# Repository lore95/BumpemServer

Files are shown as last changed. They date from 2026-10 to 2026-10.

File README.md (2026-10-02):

# bumpem

Host software for the IBMS Bump'em multi-directional perturbation system.

## Quick start
```sh
git clone <repo> && cd bumpem
python -m venv .venv && source .venv/bin/activate   # or conda
pip install -e ".[dev]"
pytest                                   # no hardware needed
bumpem monitor --sim                     # simulated board
```

## With hardware
No person attached for first tests. Stop the treadmill before `release` or `estop`.
```sh
pip install platformio
scripts/flash.sh                         # firmware v1  (scripts/flash.sh legacy = v0 reference)
bumpem ports                             # find the Teensy
bumpem info  --port /dev/tty.usbmodemXXXX
bumpem arm   --port /dev/tty.usbmodemXXXX --watch 3     # ramp to 5 N baseline
bumpem pulse A=95 --rise 50 --dur 600 --fall 0 --port /dev/tty.usbmodemXXXX --watch 2
bumpem release --port /dev/tty.usbmodemXXXX              # ramp to 0, drivers off
bumpem estop   --port /dev/tty.usbmodemXXXX              # drivers off now
```
Pulse amplitudes are relative to baseline. Protocol and parameters: `docs/PROTOCOL.md`.

ESCON setup is still done once in ESCON Studio. See `escon/README.md` and `docs/thesis/manual.pdf` §4.3.1.

Docs: `docs/knowledge/` (system facts), `docs/PROTOCOL.md`, `docs/STATUS.md`.

## Server
```sh
pip install -e ".[server,dev]"
bumpem serve --board sim                      # or --board /dev/tty.usbmodemXXXX
```
Open http://127.0.0.1:8000/docs to try every endpoint from the browser. API contract: `docs/API.md`.
While the server runs it owns the serial port: stop the board through the API (`POST /api/v1/estop`), not the CLI.

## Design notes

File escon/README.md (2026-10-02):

# ESCON configuration

**Model: maxon ESCON 70/10, part 422969** (label on the driver, photo `docs/hardware-photos/2026-09-29_escon-7010-connectors.jpg`).
Hardware reference: `ESCON-70-10-Hardware-Reference-rel9079.pdf` (maxon, 2021-08).

## I/O pins used by Bump'em (hardware reference Tables 3-17, 3-19)
| Connector | Pin | Signal | Bump'em use |
|---|---|---|---|
| J5 Digital I/O | 1 | DigIN1 | not used by the manual's wiring |
| J5 | **2** | **DigIN2** | enable ← Teensy 27/28/29/30 |
| J5 | 3, 4 | DigIN/DigOUT3, 4 | not used |
| J5 | **5** | **GND** | → ground distributor |
| J5 | 6 | +5 VDC aux out (≤ 10 mA) | **never to a Teensy pin** |
| J6 Analog I/O | 1, 2 | AnIN1+ / AnIN1− | not used by the manual's wiring |
| J6 | **3** | **AnIN2+** | setpoint ← DAC VA/VB/VC/VD |
| J6 | **4** | **AnIN2−** | → DAC GND |
| J6 | 5, 6 | AnOUT1, AnOUT2 (−4…+4 V) | **never to a Teensy pin** (negative voltage) |
| J6 | **7** | **GND** | → ground distributor |

Levels (§3.3.5–3.3.6): DigIN logic 1 > 2.4 V typ. (Teensy 3.3 V is enough), logic 0 < 1.0 V, switching delay < 8 ms.
AnIN ±10 V differential, 12-bit, 5.64 mV resolution (DAC 0–3.3 V is inside the range).

## Stanford reference configuration (`stanford/ESCON_Current_Ctrl_Config.edc`)
Downloaded 2026-09-30 from the "Config" link on https://biomechatronics.stanford.edu/bump-em (same Drive ID as manual §4.3.1).
Created 03.03.2020 for an **ESCON 70/10** with a maxon EC motor (Stanford: EC90 flat). Decoded values:
| Parameter | Value |
|---|---|
| Mode of operation | Current controller (speed limiter on) |
| Digital inputs configuration 0x00000010 | **DigIN2 = Enable**; DigIN1, 3, 4 = None |
| Analog inputs configuration 0x00000010 | **AnIN2 = Set value**; AnIN1 = None |
| Set value current | **0 V → 0 A, 10 V → 30 A (3 A/V)** |
| Max. output current limit / nominal current | 30 A / 4.06 A |
| Motor | maxon EC, 11 pole pairs, speed constant 42.1 rpm/V, 0.904 Ω, 0.892 mH, max 1960 rpm |
| Motor torque constant (tuning data) | 226.8 mNm/A |
| Analog outputs | not configured |

Nibble decoding (4 bits per input) is consistent with the manual on both fields (enable on DigIN2, setpoint on AnIN2).

**Conflict to resolve:** if the IBMS drivers carry this file (manual says to load it), the DAC's 0–3.3 V gives **0–9.9 A**, not 0–30 A as the firmware assumes (`i_full = 30`). Firmware current values are then 3.03× the real current. See `docs/STATUS.md`.

## Still to record
- ESCON Studio parameter file: not found. It can be **read back from each driver** with ESCON Studio (Windows, USB J7) and saved here. That also answers the next three lines.
- AnIN2 scaling (voltage ↔ current setpoint). Firmware assumes 3.3 V ↔ 30 A (`i_full`, `legacy/Arduino_Script.ino:242`).
- Current limit per module; which DigIN is configured as enable and which AnIN as setpoint (the manual says DigIN2 / AnIN2).
- Module (A/B/C/D) ↔ controller serial number ↔ last auto-tune date.

## Status LED (hardware reference p. 28, Table 3-23)
| Green | Red | Meaning |
|---|---|---|
| off | off | init |
| slow blink | off | disabled (ready, enable input low) |
| on | off | enabled |
| 2× | off | stopping / standstill |
| off | 1× | +Vcc over-/undervoltage, +5 V undervoltage |
| off | 2× | thermal overload, overcurrent, power stage protection, internal hardware |
| off | 3× | encoder / DC tacho cable break or polarity |
| off | 4× | PWM set value input out of range |
| off | 5× | Hall sensor pattern / sequence / frequency |
| off | on | auto-tuning identification, internal software |

Module C, 2026-10-01: **red steady, green off** = Auto Tuning Identification Error **or** Internal Software Error (Table 3-23, p. 29). Power stage off. Exact error to be read in ESCON Studio (status window). Do not run Regulation Tuning or a firmware update before diagnosing.

Module C, 2026-10-01 (later): red 1× (supply) error cleared after rework at J1, then **red 5× → ESCON Studio: "Hall Sensor Pattern Error: combination of Hall sensor signals invalid"**. Studio now connects.
J3 Hall plug (hardware reference Table 3-12): 1 Hall 1, 2 Hall 2, 3 Hall 3, 4 +5 V Hall supply (≤ 30 mA), 5 GND. Inputs have 2.7 kΩ pull-ups (p. 16): an unconnected Hall wire reads high.
Module C Controller Monitor (2026-10-01): Current Controller, DI2 = Enable, AI2 = Set Value, offset 0.0070 A, rotor position by digital Hall sensors, all other I/O unused → **matches the Stanford config** (`stanford/`). Caveat: an accidental Download on 2026-09-30 may have loaded that file. Config is not the cause of the Hall error.
ESCON Studio Diagnostics, module C (2026-10-01): motor test OK (motor turned → windings and power stage working). **Hall sensor connection test FAILED**; all three Hall states frozen while turning the drum by hand. Likely: Hall wires or Hall supply (+5 V / GND, J3 pins 4/5) broken or not connected; less likely: Hall sensors damaged. Next: J3 re-seat, cable inspection, J3 pin 4–5 ≈ 5 V, continuity J3 → motor.
**Cause found (2026-10-01): module C's J3 has wires only on pins 1–4; pin 5 (Hall GND) is empty** → Hall sensors unpowered → frozen signals, pattern error. Fix: identify the Hall cable's GND conductor from the motor's colour code (motor label → maxon datasheet), check pins 1–4 order, then connect GND to pin 5. Do not guess.
J3 (2026-10-01 photo): 1 yellow, 2 pink, 3 grey, 4 green, 5 empty; extension wires spliced under tape below J3 (pink is not a maxon Hall colour). maxon's internal Hall order is GND before +V Hall, ESCON J3 is +5 V (4) then GND (5): pin 4 may carry either. Identify via splice + motor datasheet before connecting pin 5.
**Motor model check:** maxon EC 90 flat 323772 (24 V) has 12 pole pairs, 135 rpm/V; the Stanford config says 11 pole pairs, 42.1 rpm/V → Stanford motor is another variant. Module C's motor label needed before any config download.
**Second module (2026-10-01): same J3 wiring (pin 5 empty) and same Hall error** → systematic, not a broken wire. Hypotheses: the Hall supply (GND or +V) was taken from the **distributor board** or from the **24 V supply** (RS-15-24, found disconnected). Check where the RS-15-24 outputs go and the motor's Hall supply range (datasheet, needs motor label).
Thesis check (2026-10-01): 24 V supply powers only the IAA100 (§2.7) → not the Hall supply. Hall wiring not described in the thesis; per maxon/ESCON docs, Hall GND belongs on J3 pin 5. Next: splice below J3, distributor board, motor label.
Motor identified (2026-10-01): **maxon EC 90 flat 500267** (260 W, 48 V, 11 pole pairs) → the Stanford config fits; no reload needed for the motor data. Hall colour code: from its catalog page (pending). maxon usually lists Hall GND before VHall; ESCON J3 has +5 V on 4, GND on 5 → J3 pin 4's green wire may be either. Do not connect pin 5 before checking.
Catalog page (2026-10-01): EC 90 flat 500267 = V1, 8-pin connector (Hall GND pin 6, VHall pin 3, 4.5–24 V). Module C: J2 has 4 wires (red, brown, white, **blue on shield pin 4**), J3 has 4 → 8 total = all motor pins present; **blue on J2.4 is most likely the Hall GND** → belongs on J3 pin 5. Confirm at the motor connector first.
Motor connector read (2026-10-01, mirrored wire-side numbering): blue = motor pin 6 = Hall GND, wired to J2 pin 4 (shield) instead of J3 pin 5; all other 7 wires correct. Fix: move blue to J3 pin 5. Possible reason it worked before: shield terminal → housing/earth → indirect ground path via Teensy/PC (unverified).
**Module C fixed (2026-10-01):** blue (Hall GND) moved from J2 pin 4 to J3 pin 5 → LED green, no error.
Module C Diagnostics after the fix (2026-10-01): **all tests passed**; LED green blinking (DISABLE, ready).

## Module A (left) driver configuration: `moduleA_left_2026-10-01.edc` (uploaded 2026-10-01)
= Stanford config **plus auto-tuning results**. Identical: motor data (11 pole pairs, 4.06 A nominal, 30 A limit, 1960 rpm), current-controller mode, DigIN2 = enable, AnIN2 = set value, **set value 0–10 V → 0–30 A**, offset 0.0070 A, Hall rotor detection.
26 values differ, all tuning/identification results: R 0.909 Ω, L 0.947 mH, rotor inertia, current controller P gain 186 / integral time 1041 µs (Stanford 170 / 20000), speed controller gains, Hall averaging. → auto-tuning was run after loading the Stanford file (manual §4.3.1 step 6).
**Confirms the scaling mismatch** for this driver: DAC 3.3 V = 9.9 A, firmware assumes 30 A (`i_full`).
Module C: upload still to do; if its gains equal the Stanford file (e.g. integral time 20000 µs), the accidental Download overwrote the tuning → re-run auto-tuning.

**Module A (2026-10-02): first open-loop test pulled far too strong** (same settings as C, which was gentle). Cause found: **A's J3 green and grey swapped** (green = Hall supply on pin 3, grey = Hall 3 on pin 4) → Hall supply into Hall-3 output, wrong commutation. Fix: J3 = 1 yellow, 2 pink, 3 grey, 4 green, 5 blue (as C). Then Diagnostics on A (Hall test must pass: sensor 3 was tied to +5 V while swapped) before driving again.

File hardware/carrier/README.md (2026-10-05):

# Carrier board (v1)

Replaces the breadboard: Teensy 4.1 and the MCP4728 DAC plug into sockets, each cable module gets one 5-way **pluggable** connector: its wires are screwed into a plug once, the plug pops into the board and locks with two screws.
Same connections as `docs/diagrams/cabling-4-modules.png`, plus a protection network on each force input.

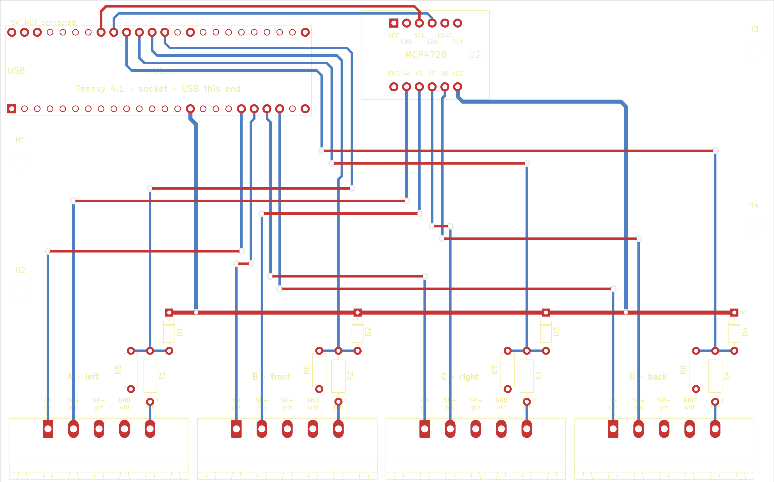
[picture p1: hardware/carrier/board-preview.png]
board

*Top view without the ground fill. Red = top copper, blue = bottom copper, yellow = silkscreen. Module wires enter at the bottom edge.*

## What is on it
| Part | Connects |
|---|---|
| U1 Teensy 4.1 (socket, USB at the left edge) | enable T27–30, force T14–17, I²C T18 SDA / T19 SCL, 3V3, GND. **VIN/5V not connected** |
| U2 Adafruit MCP4728 (socket) | VA–VD → setpoint of modules A–D, VCC 3.3 V from the Teensy |
| J1–J4 pluggable headers, one per module (A left, B front, C right, D back), pins left to right | 1 EN yellow · 2 SP+ blue · 3 SP− green · 4 GND white · 5 F brown |
| R1–R4 1 kΩ (series), R5–R8 1 MΩ (pull-down), D1–D4 BAT85 (clamp to 3.3 V) | per force input: connector F → 1 kΩ → Teensy pin; 1 MΩ to GND; BAT85 to 3.3 V |

Board 154 × 96 mm, 2 layers, through-hole parts only, 0.5 mm tracks (0.8 mm for 3.3 V), only 45° bends, ground fill on both layers (0.5 mm from other copper), 4 × M3 holes.
Spacing (measured, edge to edge): ≥ 0.74 mm between any two nets; 0.74 mm is the gap between neighbouring socket pins (2.54 mm headers).
The force tracks run under the Teensy and out past its right end, never between socket pins: ≥ 1.39 mm to any other net's pad, so a solder blob on a socket cannot reach a force signal.

**Force inputs.** The IAA100 amplifiers are trimmed to 0–3.3 V = 0–200 N (`docs/knowledge/calibration.md`). With 1 kΩ / 1 MΩ the Teensy sees 99.9 % of that (no recalibration needed). An unplugged input reads 0 N, as the ground jumpers do today. The diode only acts on a fault (amplifier mis-set or miswired): the 1 kΩ limits the current, the BAT85 dumps it into 3.3 V. If an amplifier can only be set to 0–10 V, change the pair to a divider (e.g. 22 kΩ series / 10 kΩ pull-down → 3.1 V) and recalibrate.

## Order (PCB maker)
1. Upload `fab/bumpem-carrier-gerbers.zip` to JLCPCB, Aisler, PCBWay or similar. Defaults are fine: 2 layers, 1.6 mm, any colour, HASL. The design uses no tight rules (smallest drill 0.8 mm).
2. Buy the parts below (or ask the makerspace for them).

| Qty | Part | Note |
|---|---|---|
| 1 | PCB from step 1 | |
| 2 | female header 1 × 24, 2.54 mm, 8.5 mm tall | Teensy socket (or cut from 1 × 40 strips) |
| 2 | female header 1 × 6, 2.54 mm | DAC socket |
| 4 | Phoenix Contact header **MSTB 2,5/5-GF-5,08 (1776537)**, threaded flange | on the board |
| 4 | Phoenix Contact plug **MSTB 2,5/5-STF-5,08 (1778014)**, screw flange | on each module cable: wires screwed in once (1 EN, 2 SP+, 3 SP−, 4 GND, 5 F) |
| optional | Phoenix Contact coding profile **CP-MSTB (1734634)** | keys each socket to its own plug (A's cable can't go into C's socket); check the coding scheme in Phoenix's MSTB coding guide |
| 4 | resistor 1 kΩ, 0.25 W, 1 %, axial | R1–R4 |
| 4 | resistor 1 MΩ, 0.25 W, 1 %, axial | R5–R8 |
| 4 | BAT85 Schottky diode, DO-35 | D1–D4, band (cathode) towards the 3.3 V track |
| 4 | M3 spacer + screw | |

Full list: `fab/bumpem-carrier-bom.csv`. Schematic: `fab/bumpem-carrier-schematic.pdf`. Layout: `fab/bumpem-carrier-top.pdf`, `fab/bumpem-carrier-bottom.pdf` (seen from below), both layers together `fab/bumpem-carrier-layout.pdf`. Whole KiCad project: `fab/bumpem-carrier-kicad.zip`.

**Makerspace HS Offenburg (reply 2026-10-05):** can make the board, but **without solder mask and silkscreen** (bare copper): fine for a prototype. Open with them: plated through-holes / vias? (the top-layer tracks end on socket pads, which cannot be soldered from the top under a socket); how to label pins without silkscreen (copper text or a printed label sheet).

## Assembly and first power-up
1. Solder the low parts first: resistors, diodes (check the band!), then the female headers, then the 4 MSTB headers (plug side at the board edge).
2. **No Teensy, no DAC, no modules.** Multimeter beep test: 3V3 ↔ GND must **not** beep; each connector pin 3 and 4 ↔ Teensy GND must beep; connector A pin 1 ↔ Teensy socket pin 27 must beep (same for B–D: 28, 29, 30).
3. Plug in the DAC and the Teensy (USB at the board edge). USB only, no modules: `bumpem info --port <PORT>` must answer.
4. One module at a time, 48 V off: screw that module's 5 wires into a plug (order as printed on the board: EN yellow, SP+ blue, SP− green, GND white, F brown), plug it in, tighten the two flange screws. Then repeat `scripts/open_loop_test.sh` for that module.

## Before ordering: check in KiCad (5 minutes)
- Open `bumpem-carrier.kicad_pro` → PCB editor → View → 3D viewer: the MSTB headers' plug openings must face the bottom board edge.
- Hold a Teensy and the DAC over a 1:1 print of `fab/bumpem-carrier-layout.pdf`: pins over the holes, Teensy USB at the left edge.

## Change the design
Do not edit the KiCad files by hand; they are generated.
- Connections and part values: `netlist.py`. Placement and routing: `gen_carrier.py`. Schematic drawing: `gen_schematic.py`.
- Rebuild and check everything: `./build.sh` (needs KiCad 8). It must print 0 ERC violations and 0 DRC / schematic-parity violations.

Sources: Teensy 4.1 pin order from XenGi/teensy_library (MIT); MCP4728 breakout pad positions from adafruit/Adafruit-MCP4728-PCB; pins from `firmware/src/main.ino` and `docs/knowledge/wiring.md`.

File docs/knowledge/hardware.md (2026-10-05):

# Hardware

Sources: `docs/thesis/thesis.pdf` §2.3–2.9, §3.1; `docs/thesis/manual.pdf` §3, §4.2; `legacy/Arduino_Script.ino:47-64`.

## Modules
| Module | Letter | Direction (thesis Fig. 11) | Force pin | Enable pin (ESCON DigIn2) | DAC ch |
|---|---|---|---|---|---|
| 1 | A | left  | A0 (pin 14) | 27 | A |
| 2 | B | front | A1 (pin 15) | 28 | B |
| 3 | C | right | A2 (pin 16) | 29 | C |
| 4 | D | back (not in the thesis; confirmed by the project lead 2026-10-02) | A3 (pin 17) | 30 | D |

Diagonals: `ab` = front-left, `bc` = front-right (thesis Fig. 11 d/e). `cd`, `da` exist in firmware, untested.

**Setup 2026-10-02:** A (left), C (right) and D (back) mounted and run in the open-loop test; B (front) not installed. Earlier, D was out of service (thesis §7: "mechanical damage"; manual §2: "a new motor driver needs to be purchased"). Firmware still boots with `ch_D = 0`: `bumpem set ch_D 1` after each power-up.

## Per-module chain
Teensy 4.1 → I²C (SDA 18, SCL 19) → MCP4728 DAC (12-bit, 0–3.3 V) → ESCON 70/10 AnIn2 (J6.3) → Maxon BLDC (EC) motor → reel drum → rope → DYMH-103 load cell → Futek IAA100 → Teensy ADC.

## Motor (all modules' labels, 2026-10-01)
**maxon EC 90 flat Ø90 mm, 260 W, 48 V, with Hall sensors, part 500267** (maxon product page): 11 pole pairs, no-load speed 1960 rpm, torque constant **231 mNm/A**, speed constant 41.3 rpm/V, terminal resistance 0.844 Ω, inductance 1.07 mH, stall current 56.9 A. Matches the Stanford ESCON config (11 pole pairs, 1960 rpm, 226.8 mNm/A). Firmware `kt = 0.1524` differs (see STATUS).
Hall colour code: catalog page PDF (to be added to `docs/reference/`).

## Power
- 48 V DC per module → shunt regulator / brake chopper → ESCON (thesis §2.4).
- 24 V DC → IAA100.
- Common ground via distributor. Logic 3.3 V.

## Sensing
- **Found 2026-10-05:** a 4th IAA100 still paired with a **DYMH-103 200 kg, 1.0 mV/V** (others: 100 kg, 1.6 mV/V) → ~3× less signal per N, so ~3× more noise and ±0.3 % of 1962 N ≈ ±6 N. Possibly thesis sensor S4 (calibration.md). Check with 6 / 8 / 12 kg before use; small errors → firmware `gain_X` / `offset_X`.
- Load cell DYMH-103. Thesis Table 1 says 100 kg max; text says 1000 N (§3.1) / 980 N (§8). Excitation 10 V, sensitivity 1.6 mV/V.
- IAA100 gain set via DIP switches + zero/span pots: 0–3.3 V ↔ 0–200 N (§3.1–3.2).
- Teensy ADC 10-bit (`ADCresolution = 1023`, `.ino:39`).

## Mechanical
- 80×80 mm aluminium profiles, floor mounts, height adjustable to CoM (§2.9).
- Breakaway cable per rope (§2.1).
- No reflective parts (mocap) (§2.3).

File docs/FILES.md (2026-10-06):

# File index

In git: code, tests, scripts, `.md` docs, ESCON `.edc` files, the cabling PNG. **Local only** (`.gitignore`, ask the project lead for copies): `docs/thesis/`, `docs/reference/`, `docs/hardware-photos/`, `escon/*.pdf`, `legacy/`, `firmware/legacy/`, `firmware/tools/`, other `docs/diagrams/` files.

| Path | Purpose |
|---|---|
| `CLAUDE.md` | Agent instructions |
| `docs/thesis/thesis.pdf` | Master thesis (Palanisamy, 2026). Primary reference |
| `docs/thesis/manual.pdf` | Bumpem user manual |
| `docs/knowledge/*.md` | Extracted facts with source citations |
| `docs/knowledge/wiring.md` | Connection list for 4 modules (text source of the wiring diagram) |
| `docs/knowledge/controller.md` | Stanford build guide, Controller section (reference design for controller API) |
| `docs/knowledge/perturbation_definitions.md` | Lab-standard perturbation terms (PTO, start/end, phases, amplitude) |
| `hardware/carrier/` | Carrier PCB (KiCad 8): `README.md` (order, BOM, assembly), `netlist.py` (connections), `gen_schematic.py` / `gen_carrier.py` (generate the KiCad files), `build.sh` (rebuild + ERC/DRC/parity + fab files), `fab/` (gerber zip, BOM, schematic and layout PDFs) |
| `docs/diagrams/cabling-4-modules.png` | Breadboard cabling, Teensy + MCP4728 → modules A–D, real wire colours, same pattern per module (current state: force inputs 14–17 grounded, brown force wires unplugged; D out of service). Generated by `make_cabling_4.py` (local only) |
| `docs/power-estop-checklist.md` | Power + e-stop checklist (self-check; no technician): supply ratings, mains inspection, capacity, earthing, e-stop, sign-off |
| `docs/tests/open-loop-test-module-C.md` | Preliminary open-loop test: Teensy drives module C without force sensor (settings, wiring, steps) |
| `docs/tests/power-checks-module-C.md` | Self-contained electrical test spec before first 48 V power-on (continuity, polarity, e-stop, shunt threshold, first power-on) |
| `docs/TODO.md` | Daily checklist for lab and software work (ordered, with commands) |
| `docs/QUESTIONS.md` | Open questions for the previous student (answers go back into the docs) |
| `docs/API.md` | Server HTTP/WebSocket API, contract for every client (1.0-draft) |
| `docs/hardware-photos/` | Lab photos with notes (`README.md` lists what each shows and what is unknown) |
| `docs/PROTOCOL.md` | Serial protocol (v0 legacy, v1 plan) |
| `legacy/Arduino_Script.ino` | Original firmware (read-only) |
| `legacy/MATLAB_script.m` | Original gait detection + triggering (read-only) |
| `firmware/` | PlatformIO project, Teensy 4.1, firmware v1 |
| `firmware/tools/loadcell_check/` | Recreated calibration sketch (A1, 200 ms, `ADC \| Voltage \| Force`). `scripts/flash.sh loadcell` |
| `firmware/legacy/` | PlatformIO project building `legacy/Arduino_Script.ino` (v0 reference) |
| `escon/stanford/` | Stanford reference ESCON 70/10 config (`.edc`), decoded in `escon/README.md` |
| `docs/reference/maxon-500267-catalog-page.pdf` | maxon EC 90 flat 260 W catalog page (motor data, 8-pin connector pinout V1) |
| `docs/reference/meanwell-rsp-2000-spec.pdf` | Mean Well RSP-2000 datasheet (48 V supply: CN501 pins, remote ON-OFF for the e-stop) |
| `docs/reference/maxon-235811-dsr-70-30-operating-instructions.pdf` | maxon DSR 70/30 shunt regulator / brake chopper (terminals 1–10, DIP threshold, LEDs, 8800 µF) |
| `docs/reference/stanford-bumpem-build-guide.pdf` | Stanford Bump'em build instructions (source of `knowledge/controller.md`) |
| `escon/` | ESCON 70/10 notes + J5/J6 pin table (`README.md`), maxon hardware reference PDF; parameter file (missing) |
| `bumpem/protocol.py` | v1 message types, parser, command builders (mirrors PROTOCOL.md) |
| `bumpem/device.py` | `Board` client (request/ack, telemetry, estop) over `SerialLink` or sim |
| `bumpem/sim.py` | `SimLink`: simulated board speaking protocol v1 |
| `bumpem/gait.py` | FS/TO detector, port of MATLAB logic |
| `bumpem/experiment.py` | Perturbation sequence + FS target generation |
| `bumpem/recovery.py` | Balance-recovery interface + fixed-wait stand-in (`TODO(recovery)`: lab algorithm) |
| `bumpem/datalog.py` | CSV logs (MATLAB-compatible headers) |
| `bumpem/vicon.py` | Vicon DataStream client (stub) |
| `bumpem/geometry.py` | Perturbation angle → per-module amplitudes (Vicon axes, D16), reachable directions |
| `bumpem/cli.py` | `bumpem` command (incl. `bumpem serve`, `bumpem perturb ANGLE AMPLITUDE`) |
| `bumpem/server.py` | FastAPI server: `board` and `host` endpoints of `docs/API.md` (incl. `/perturbation`, `/geometry`) + WebSocket stream; serves `../BumpemUI/web` at `/ui/` |
| `tests/` | pytest, no hardware needed (`test_server.py`: API on the simulator) |
| `scripts/open_loop_test.sh` | Guided open-loop test: `A`, `C`, or `AC` (both, same pulse started in the same control cycle): settings, dry run, 48 V prompts, pulses 5/10/20 N; Ctrl+C = ESTOP |
| `scripts/flash.sh` | Build + upload firmware |

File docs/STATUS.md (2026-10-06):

# Status

## Done
- **"No reply" timeouts solved (2026-10-06): USB connection, not software.** With no server and nothing sent, the Mac stopped receiving 0.1–1 s after each port open while the Teensy kept running (uptime counting, no reboot); same with 48 V and 24 V off. Teensy sits behind a USB 2.0 hub (adapter). Moved to another port/cable: 100 telemetry lines/s steady, PING/SET/INFO/GET answered. If timeouts come back: check the line rate first (`bumpem monitor`), then the cable/port. Serial log (`BUMPEM_SERIAL_LOG=<file>`) and the `[reader alive, last line … s ago]` timeout text stay as diagnostics.
- **Test pulls work on A, C and D (2026-10-06)** (`bumpem serve --testing`, testing page). A first did nothing: loose pin contact on A's breadboard wiring (reseated). Breadboard contacts are a known weak point until the carrier PCB. Open-loop test pull ≈ 0.08 A per N entered, ≈ 1 N at the rope per N before friction (kff 2, i_full 30 vs real 9.9 A, kt 0.152 vs 0.227 Nm/A); 2–5 N barely moves a motor, 10–20 N visibly. Next: production page (Arm with tension from the force sensors) once C's ground wire is repaired; `i_full` = 9.9 decision (`docs/knowledge/control.md`).
- **Module D pulled far too hard on a 2–5 N test pull (2026-10-06): wiring.** D's green wire (AnIN2−, J6 pin 4) was on the breadboard **+ rail (3.3 V)** instead of the − rail; moved by the user. A and C barely moved: open-loop test pull commands ~0.14 V → ~0.4 A at 5 N (kff 2, i_full 30 vs the real 9.9 A full scale, `docs/knowledge/control.md`). Next: 48 V off → arm at baseline 20 N → J6 pin 3–4 ≈ 0.55 V on A, C, D; then test pulls again.
- **Stuck-at-power-up hint (2026-10-05):** if the DAC is not found on I²C at boot, firmware v1 only prints `E,0,FAULT,DAC init failed` every second and answers nothing (`main.ino:450-452`); `Board` now says so on a timeout (check DAC VCC / GND / SDA T18 / SCL T19, replug USB). Seen on the real board after rewiring: `bumpem info` → no reply.
- **Exclusive serial port (2026-10-05):** `SerialLink` opens the Teensy port exclusively; a second `bumpem` program gets "port busy". Seen before: test pulls / ARM / INFO timing out at random ("no reply to GET") when two programs read the port. Advisory lock: it stops other `bumpem` programs, not tools that ignore locks (e.g. Arduino serial monitor).
- **Two modes (2026-10-05, D19), server 0.3.0:** `bumpem serve --testing` → testing page (one pull per motor: force + duration, no arming, settings restored after each pull); default `--production` → full UI. Each mode refuses the other's commands. 45 tests pass; both pages checked in Chrome on the simulator.
- **Channels at connect (2026-10-05, D18):** `bumpem serve` sets ch_A..D to `--modules` (default ACD); if the board isn't DISARMED at connect, it sets them when it next reports DISARMED. Seen on the real board before: B on / D off (firmware defaults) → back refused, back-left pulled only A. **Fixed 2026-10-05:** two simultaneous `POST /connect` (double click) closed the first link while in use (504) and revived its ping thread on the closed port (`PortNotOpenError`); connects are now serialized and each connection has its own ping stop. Likely also the earlier `no reply to ARM`.
- **Browser UI (2026-10-05):** `bumpem serve` serves `../BumpemUI/web` at http://127.0.0.1:8000/ui/ (D17); first UI built and tested on the simulator (BumpemUI STATUS). **Fixed:** the WebSocket stream returned 404 under uvicorn (missing `websockets` library) → added to the `server` extra; reinstall with `pip install -e ".[server,dev]"`. 40 tests pass.
- **Perturbation by angle (2026-10-02), server 0.2.0:** `POST /api/v1/perturbation` (angle + amplitude + phase 1 / duration / phase 2 + delay → one PULSE) and `GET /api/v1/geometry`; CLI `bumpem perturb ANGLE AMPLITUDE`. Angles in Vicon axes (0 front, +90 left, −90 right, 180 back), split over the two neighbouring cables as the legacy firmware did (45° → 1/√2 each). Angles needing a disabled channel are refused. `bumpem/geometry.py`, 39 tests pass (simulator). Not yet run on the hardware (D16).
- **Module D set up (back) and run with the open-loop script (2026-10-02).** Mounted: A left, C right, D back; B (front) not installed → reachable: left, back, right and the back diagonals. Firmware boots with `ch_D = 0`: `bumpem set ch_D 1` after each power-up.
- **Carrier board v1 designed (2026-10-02), not ordered:** `hardware/carrier/` (KiCad 8 project, generated by `build.sh` from `netlist.py`). Teensy 4.1 + MCP4728 on sockets, one 5-way screw terminal per module (EN, SP+, SP−, GND, F; same as `cabling-4-modules.png`), force-input protection (1 kΩ series, 1 MΩ pull-down, BAT85 clamp to 3.3 V). 2 layers, through-hole, 154 × 96 mm, pluggable module connectors (Phoenix MSTB 2,5, 2026-10-05). ERC 0, DRC 0, schematic parity 0. Spacing ≥ 0.74 mm everywhere; force tracks ≥ 1.39 mm from other pads (rerouted around the Teensy end). Module D labelled back. Gerbers + BOM in `hardware/carrier/fab/` (D15).
- Git repositories (2026-10-02): `BumpemServer` and `BumpemUI`, branch `main`, local only (not pushed). Repo filtered to the code and docs in use; thesis, reference PDFs, photos, `legacy/`, `firmware/legacy/`, `firmware/tools/` and diagram sources stay on disk, ignored (list in `docs/FILES.md`, D14). Cabling diagram: `docs/diagrams/cabling-4-modules.png` (A–D, same pattern).
- **Modules A + C under Teensy control (2026-10-02):** open-loop tests passed for A alone, C alone and **A + C together** (`scripts/open_loop_test.sh AC`, same pulse started in the same control cycle). No force measured yet.
- **Module A open-loop test passed (2026-10-02)** after fixing its J3 (green/grey swapped → too-strong pull). Test script now: 400 ms pulses (was 600), red/green 48 V banners before/after the dry run.
- **First motor drive with firmware v1 (2026-10-02):** open-loop test of module C (`scripts/open_loop_test.sh`, kp = kd = 0, kff 2, baseline 2 N, fmax 30 N, only ch_C): **motor pulled correctly, tug grew with 5 → 10 → 20 N, release back to normal**; module A idle as intended. Chain Mac → USB → Teensy → DAC VC → ESCON → motor confirmed. No force measured (amplifier not connected).
- **`bumpem serve` (2026-10-02):** `bumpem/server.py`, FastAPI, all `board` endpoints of `docs/API.md` + WebSocket stream (telemetry thinned, events, estop). Watchdog `wd_ms` (default 1000) + 300 ms ping when on real hardware. 31 tests pass (7 server tests on the simulator). Not yet run against the Teensy.
- Project lead's Mac set up (2026-09-30): conda env `BumpemHome` (Python 3.12), `pip install -e ".[dev]"`, pytest 24 passed.
- Repo scaffold. Legacy code archived in `legacy/` untouched.
- Knowledge extracted from thesis + manual + legacy code → `docs/knowledge/`.
- `docs/PROTOCOL.md` v0 documented from firmware.
- Firmware builds with PlatformIO (not yet flashed). Pinned: platform teensy@6.0.0 (framework-arduinoteensy 1.162.0), Adafruit MCP4728@1.0.10, Adafruit BusIO@1.17.4.
- **Firmware v1** (`firmware/src/main.ino`, protocol v1): compiles (PlatformIO, 2026-09-29), **not yet run on hardware**. v0 reference build: `firmware/legacy/`, compiles.
- **Desk test on Teensy 16922250 passed (2026-09-29)**, no modules wired. Original calibration sketch output saved (`firmware/tools/loadcell_check/original_output_2026-09-29.txt`), then v1 flashed. Checked: `info` (proto 1, fw 1.0.0), 32 params at v0 defaults, disarmed pulse rejected, ARM/pulse/abort/ESTOP/re-ARM/release, rejections (disabled channel, > fmax_n), event order. DAC loopback (VA–VD jumpered to pins 14–17, open-loop kp = kd = 0): code 639 → 30.7–31.5 N (0.51 V, expected 31.2 N), code 3199 → 155.6–157.2 N (expected 156.2 N), each channel alone, order A–D correct, DAC supply ≈ 3.29 V. Loop max 1.76 ms, overruns 1 (boot), tx_drops only while no host reads. Board left DISARMED with defaults. System map (`docs/diagrams/`) updated to this state.
- Wiring for 4 modules documented: `docs/knowledge/wiring.md` + `docs/diagrams/wiring-4-modules.*` (from manual p. 3 table + `main.ino` pins). ESCON connector pin numbers still unknown (need model).
- Workspace split (D11): this folder = BumpemServer, UI in `../BumpemUI`. Tests (24) and both firmware builds re-checked after the move. System map updated.
- `docs/API.md` 1.0-draft: server API contract (D9, D10). Not implemented.
- Recovery hook: `bumpem/recovery.py` + `Scheduler(recovery=...)`, stand-in `FixedWaitRecovery` (D8). Search `TODO(recovery)` to insert the lab algorithm.
- Python mirror of v1: `protocol.py`, `device.py` (`Board` client), `sim.py` (`SimLink`), CLI. 24 tests pass.
- Python package skeleton: protocol parser, gait detector port, sequence generator, simulator, CLI. Tests pass (no hardware).

## Next
**Next session starts with:** try `bumpem perturb` on A/C/D (open-loop settings of `scripts/open_loop_test.sh`, `set ch_D 1`, e.g. `perturb 135 10`, `perturb 180 10`, `perturb -90 10`); then API step 2 (PTO on gait events) and 3 (trials), `docs/API.md` `planned`. Hardware: e-stop wiring (RSP-2000 CN501 pins 7 + 11, `knowledge/wiring.md`) and test; then 24 V + IAA100 amplifiers (range ≤ 3.3 V check) → closed-loop test; repeat a pulse through `bumpem serve`. Before final testing: driver config uploads/auto-tuning, firmware `i_full` 9.9 and `kt` 0.231.

Day-to-day checklist: `docs/TODO.md` (keep it in step with this list).

0. ~~Desk test~~ **passed 2026-09-29** (see Done). Next hardware step: wire the modules (Blocked: ESCON pinout, wire identification). Remove the loopback jumpers (DAC VA–VD → pins 14–17) before connecting load cells.
1. Bench, **no person attached**: `scripts/flash.sh legacy` → confirm 5 N baseline on A/B/C (v0 reference). Then `scripts/flash.sh` → `bumpem arm --port P --watch 5` → baseline matches v0.
2. `bumpem pulse A=95 --rise 50 --dur 600 --fall 0 --port P --watch 2` (= v0 `a`). Compare peak/rise with `knowledge/results.md`. Check `bumpem stats` (loop overruns, tx_drops).
3. ~~Server~~ done (sim). Next: run `bumpem serve --board <PORT>` against the Teensy (repeat the open-loop pulses via `/docs`).
4. Minimal web UI in `../BumpemUI` (its own STATUS.md): connect, arm, pulse, stop, live force plot. Then the gait-phase picker (needs: walking or running? images?).
5. Host layer (`planned` endpoints): angle → channel amplitudes, PTO scheduling, trials, measured-vs-commanded (±2 SD, baseline = first 3 s, D7). `experiment.py` still speaks v0 letters; port it then.
6. Validate `bumpem/gait.py` against a recorded MATLAB `Log_event_data_*.csv`.

## Blocked / needed
- **Module C first power-on (2026-09-30):** power checks T0–T7 passed (`docs/tests/power-checks-module-C.md`); 2026-10-01: supply error at J1 fixed; ESCON Studio connects; current error **Hall Sensor Pattern Error**; Controller Monitor shows Stanford-equivalent config; Diagnostics: motor test OK, **Hall connection FAILED**, all 3 Hall states frozen. **J3 pin 5 (Hall GND) empty on module C and on a second module, same Hall error on both** → systematic. Motor catalog (500267, V1): 8 motor wires all present; **Fixed 2026-10-01:** blue (Hall GND) moved to J3 pin 5 → ESCON Diagnostics all passed, LED green blinking (disabled, ready). Same fix likely needed on the second module. Next: identify GND conductor via motor colour code (need motor label + J3 photo), connect, re-test; config backup.
- **Power supplies disconnected, e-stop not installed (2026-09-30).** Module wiring otherwise as documented. Power chain + e-stop notes: `knowledge/wiring.md` → "Power supplies and e-stop". E-stop pins found: RSP-2000 **CN501 pin 7 + pin 11**, NO contact, short = 48 V off (datasheet in `docs/reference/`). No technician: mains side inspected only (no 230 V work by the project lead), faults via the university; checklist `docs/power-estop-checklist.md`; supervisor asked about DGUV V3. `docs/TODO.md` reordered by danger/blocking (2026-09-30); step 1 = technician.
- **Call with the previous student (week of 2026-10-05):** all open questions in `docs/QUESTIONS.md`. After the call, move each answer into the doc named next to it and remove the matching items here.
- **Control board found, unwired (2026-09-29).** Teensy 4.1 (USB serial number 16922250, macOS port `/dev/cu.usbmodem169222501`) sits on a breadboard with the MCP4728 only; no wires to any module. ESCON side: loose jumper cable (`docs/hardware-photos/`). The board runs an unknown single-channel load-cell test sketch (`ADC: … | Voltage: … | Force: … N`, ~6 lines/s, same 200 N / 3.3 V scaling); flashing erases it for good (source not in repo; ask the lab first).
  Rewiring to modules needs: ESCON model (driver label) → connector pinout; each wire identified by continuity and labelled; wiring per thesis Fig. 7 + manual p. 3 table. Blocks Next 1–2 beyond the desk test.
- **Cable traced on module C (2026-09-30, `knowledge/wiring.md`):** yellow J5.2 enable, blue J6.3 setpoint+, green J6.4 setpoint−, brown IAA100 Out (force), white → board in frame, 2 spares. Frame board = this module's **ground distributor** (ESCON J5.5 + J6.7 + IAA100 GND → white wire). All 7 wires traced to jumper ends: black = enable, red (F) = setpoint +, orange = setpoint −, blue = force, purple = GND, yellow/white spare. This driver = **module C** (right): black → Teensy 29, red → DAC VC, orange → DAC GND, blue → Teensy 16, purple → Teensy G. Next: trace A and B, label jumper ends. To do: module letter, jumper-end colours, other 3 drivers.
- Stanford reference ESCON config (`escon/stanford/`): DigIN2 = Enable, AnIN2 = Set value, all other inputs unused, no analog outputs. So the 2 extra wires per driver, if on this config, go to unused pins. Colour ↔ pin still needs a continuity test.
- **ESCON model known: 70/10 (422969)**; hardware reference + J5/J6 pin table in `escon/`. Still needed: wire colour ↔ J5/J6 position on each driver (each has 7 wires, 5 needed: J5.2, J5.5, J6.3, J6.4, J6.7); J5.6 (+5 V) and J6.5–6 (AnOUT, ±4 V) must never reach a Teensy pin.
- ESCON parameter file → `escon/`: can be read back from each driver with ESCON Studio (Windows, USB J7) instead of waiting for the Drive link.
- A recorded MATLAB log pair (event + perturbation CSV) → `tests/data/`.
- Vicon DataStream SDK Python bindings (installed with the SDK; check version on lab PC).
- **Balance-recovery algorithm** (D7): source code, language, inputs (which markers/segments, rate), output (recovered yes/no? score?), latency. Needed to define the hook.

## Open issues found in legacy code
- **Motor = maxon EC 90 flat 500267 (2026-10-01): kt = 0.231 Nm/A** (datasheet) vs firmware `kt = 0.1524`. Correct together with `i_full` after the first test.
- **ESCON setpoint scaling CONFIRMED on module A's driver (2026-10-01): 0–10 V → 0–30 A** (`escon/moduleA_left_2026-10-01.edc`). Original note:  Stanford config (`escon/stanford/`) = 0–10 V → 0–30 A; firmware assumes 3.3 V → 30 A (`i_full`). If the IBMS drivers hold that config, real current = firmware value / 3.03 and the DAC ceiling is 9.9 A, which fits the thesis peak forces. Verify by uploading each driver's config (ESCON Studio) before touching `i_full`/`kff` (`knowledge/control.md`).
- Impulse duration 600 ms in code vs 300 ms in thesis §4.3. Which was used for the thesis data?
- Setup prints "baseline = 10 N" but `baselineForce = 5.0` (`.ino:119` vs `:36`).
- DAC saturated from feedforward above ~32 N target (see `knowledge/control.md`).
- No 200 N clamp; stop halts forever; serial port contention blocks the Serial Monitor stop (see `knowledge/safety.md`).
- Module 4: mechanical damage (thesis) vs missing driver (manual).
- Load cell sensor ↔ module mapping unconfirmed.
- Firmware vs Stanford guide (`knowledge/controller.md`): feedforward ×7.5 (guide: ×1 with kt = 0.89·kt_nominal); no force filter (guide: 2nd-order Butterworth 60 Hz); D term on raw Δf/Δt in ms (guide: 3-step averaged derivative of error); one gain set (guide: separate gains for low-force tracking vs perturbation). Is `kt = 0.1524` nominal or measured?

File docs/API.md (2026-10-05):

# bumpem server API

The contract between the bumpem server and every client (the web UI in `BumpemUI`, MATLAB, scripts,
future apps). Clients use only this API, never the Python internals (DECISIONS D10).

**Version:** 1.0-draft. Server 0.2.0 (2026-10-02): `board` and `host` endpoints implemented in `bumpem/server.py` (tests `tests/test_server.py`, `tests/test_geometry.py`, simulator). `planned` endpoints not implemented. Breaking changes bump the major
version and the path prefix (`/api/v1` → `/api/v2`). Additions do not.

**Status tags:** `board` = maps directly onto protocol v1 (`docs/PROTOCOL.md`), **implemented**. Interactive test page: `http://127.0.0.1:8000/docs`.
`host` = computed by the server, then sent as protocol v1 commands, **implemented**.
`planned` = needs gait events / trials (PTO, scheduling); schema is a proposal.

## Basics
- Server: `bumpem serve`, listens on `http://127.0.0.1:8000` (this PC only). Other hosts only if started with `--host`.
- UI: the same server serves the browser UI (`../BumpemUI/web`) at **`http://127.0.0.1:8000/ui/`**; `/` redirects there. Other folder: `bumpem serve --ui PATH`. Same origin, so the UI needs no cross-origin setup.
- One server per PC. The server alone opens the Teensy's serial port (or the simulator).
- JSON everywhere. Units: force N, time ms, angle degrees.
- Angle (Vicon Forward/Left/Up axes, counter-clockwise seen from above): **0 = front, +90 = left, −90 = right, 180 = back**. Any value is accepted and normalised to (−180, 180]. The angle is the direction the subject is pulled.
- Modules: A +90 (left), B 0 (front), C −90 (right), D 180 (back). A module is available when its channel is on (`ch_A`…`ch_D` = 1). **On connect the server sets the channels to the mounted modules** (`bumpem serve --modules ACD`, default `ACD`; `--modules ""` keeps the firmware's power-up defaults A, B, C on, D off). Channels only change while DISARMED: if the board is armed (or in ESTOP) at connect, the server sets them as soon as it next reports DISARMED. `PATCH /params` can still change them. Setup 2026-10-02: A, C, D mounted, B not installed → reachable +90 … 180 … −90 (left, back, right and the back diagonals).
- Pulse terms follow `docs/knowledge/perturbation_definitions.md`: amplitude is relative to baseline; duration runs start → end, ramps included.

## Errors
HTTP 4xx/5xx with:
```json
{"error": {"code": "board_rejected", "message": "exceeds fmax_n"}}
```
| code | HTTP | meaning |
|---|---|---|
| `invalid` | 422 | request failed validation before reaching the board |
| `board_rejected` | 409 | board answered `A,ERR` (message = board reason) |
| `not_connected` | 409 | no board or simulator connected |
| `board_timeout` | 504 | no reply from the board |
| `wrong_mode` | 409 | endpoint belongs to the other server mode (testing / production) |

## Endpoints

### Connection
| Method | Path | Body | Returns | Status |
|---|---|---|---|---|
| GET | `/api/v1/info` | | `{"server": "0.3.0", "api": "1.0", "mode": "production" \| "testing", "port": "sim", "board": {...INFO fields} or null}` | board |
| GET | `/api/v1/ports` | | `["/dev/tty.usbmodem123", ...]` | board |
| POST | `/api/v1/connect` | `{"port": "COM7"}` or `{"port": "sim"}` | `info` | board |
| POST | `/api/v1/disconnect` | | `{}` | board |

### Board state and parameters
| Method | Path | Body | Returns | Status |
|---|---|---|---|---|
| GET | `/api/v1/status` | | `{"state": "ARMED", "pulse_id": 0, "telemetry": {...last}}` | board |
| GET | `/api/v1/params` | | `{"kp_track": 0.24, ...}` (all protocol v1 parameters) | board |
| PATCH | `/api/v1/params` | `{"baseline_n": 5, "kff": 7.5}` | updated params | board |

`PATCH` applies keys one by one and stops at the first rejection; the error names the key.

### Modes
`bumpem serve --testing` or `--production` (default). The UI at `/ui/` follows the mode (production page / testing page), and the server refuses what belongs to the other mode with 409 `wrong_mode`:

| Mode | Allowed | Refused |
|---|---|---|
| production | everything below except `/test/pull` | `POST /test/pull` |
| testing | connection, status, params, `POST /test/pull`, `abort`, `release`, `estop`, `clear`, stream | `POST /arm`, `POST /pulse`, `POST /perturbation` |

### Test pull (`host`, testing mode)
One pull on one motor, without leaving the system armed:
```json
POST /api/v1/test/pull
{"module": "C", "force_n": 5, "dur_ms": 400}
→ {"pulse_id": 3, "module": "C", "force_n": 5, "dur_ms": 400}
```
The server, in one call: saves the parameters → open loop (gains 0, `kff` 2), `baseline_n` 0, `fmax_n` = `force_n`, `arm_ms` 0, only `module` enabled → `ARM` (target 0 N, rope stays slack) → one `PULSE` (50 ms ramps, `dur_ms` 100–1000 incl. ramps) → `RELEASE 0` → restores the parameters. Starts only from DISARMED or ESTOP (else 409 `board_rejected`); one test pull at a time. Force is calculated from the motor current (open loop), not measured. `estop` works throughout.

### Actions
| Method | Path | Body | Status |
|---|---|---|---|
| POST | `/api/v1/arm` | | board |
| POST | `/api/v1/abort` | | board |
| POST | `/api/v1/release` | `{"ms": 1000}` | board |
| POST | `/api/v1/estop` | | board |
| POST | `/api/v1/clear` | | board |

`estop` is never queued behind another request. Only `release` and `estop` drop tension:
stop the treadmill first (`docs/knowledge/safety.md`).

### Pulses
Channel form (`board`): exactly one protocol v1 `PULSE`. The server assigns the id.
```json
POST /api/v1/pulse
{"amps": {"A": 65.71, "B": 65.71}, "delay_ms": 0, "rise_ms": 50, "dur_ms": 600, "fall_ms": 0}
→ {"pulse_id": 12}
```
Perturbation form (`host`): the server converts angle → channel amplitudes, then sends one `PULSE`.
```json
POST /api/v1/perturbation
{"angle_deg": 135, "amplitude_n": 20, "phase1_ms": 50, "dur_ms": 400, "phase2_ms": 50, "delay_ms": 0}
→ {"pulse_id": 13, "amps": {"A": 14.14, "D": 14.14}}
```
- `amplitude_n`: resultant force above baseline along `angle_deg`. `phase1_ms` / `phase2_ms`: ramp up / ramp down (acceleration phases one and two, `perturbation_definitions.md`); `dur_ms` start → end, ramps included; `delay_ms`: board-side delay before the start.
- Split: on a module's axis that module alone gets `amplitude_n`. Between two neighbouring modules (90° apart) the first gets `amplitude_n·cos(Δ)`, the second `amplitude_n·sin(Δ)`, Δ = angle past the first module. At 45° each gets `amplitude_n/√2`, the rule of the original firmware (`legacy/Arduino_Script.ino:82`). Assumes horizontal cables at right angles.
- An angle needing a module whose channel is off → 422 `invalid`, message names the module. Force limits stay on the board (`fmax_n` → 409 `board_rejected`).
- At baseline the cables do not cancel when a module is missing: with B not installed, the subject feels a constant pull of `baseline_n` towards D (back).

PTO (`planned`): adds `"pto": {"mode": "ms" | "stance_pct" | "cycle_pct", "value": 20}, "trigger": {"event": "FS", "side": "any"}` → waits for the next matching gait event, response adds `"scheduled": "same_fs" | "predicted_fs"`. `cycle_pct`: % of the gait cycle after the trigger foot strike (running: stance 0–40, float 40–55, swing 55–85, float 85–100, thesis Fig. 1); the server converts it with the measured stride time. The UI's gait-phase picker produces it.

| Method | Path | Returns | Status |
|---|---|---|---|
| GET | `/api/v1/geometry` | `{"convention": "...", "modules": {"A": {"angle_deg": 90, "enabled": true}, ...}, "reachable": [{"from_deg": 90, "to_deg": -90}]}` (arcs counter-clockwise from → to; `enabled`/`reachable` null when no board is connected) | host |

### Trials (`planned`)
| Method | Path | Body |
|---|---|---|
| POST | `/api/v1/trials` | trial config (below) → `{"trial_id": "20260929_142301"}` |
| POST | `/api/v1/trials/{id}/start` | |
| POST | `/api/v1/trials/{id}/stop` | ends scheduling; does not release tension |
| GET | `/api/v1/trials/{id}` | progress, log file paths, per-pulse measured vs commanded |

```json
{
  "perturbations": [{"angle_deg": 90, "amplitude_n": 95, "phase1_ms": 50, "dur_ms": 600, "phase2_ms": 0}],
  "blocks": 5, "shuffle": true,
  "pto": {"mode": "stance_pct", "value": 20},
  "interval": {"steps_min": 50, "steps_max": 75, "count_from": "recovery"},
  "recovery": {"method": "fixed_wait", "wait_s": 10},
  "baseline_window_s": 3
}
```
`recovery.method` is `fixed_wait` (stand-in, D8) until the lab algorithm is added. Values above are examples.

## Live stream (WebSocket)
`ws://127.0.0.1:8000/api/v1/stream?telemetry_hz=30`

Server → client, one JSON object per message:
```json
{"type": "telemetry", "t_ms": 1234, "state": "ARMED", "pulse_id": 0,
 "target": {"A": 5.0, ...}, "measured": {"A": 5.1, ...}, "dac": {"A": 1846, ...}}
{"type": "event", "t_ms": 1300, "kind": "PSTART", "args": ["12"]}
{"type": "gait", "t_s": 12.345, "event": "FS_VALID", "side": "left"}        // planned
{"type": "trial", "trial_id": "...", "done": 3, "total": 25}                   // planned
```
Telemetry is thinned to `telemetry_hz` for display. Logs always keep the full board rate.

Client → server: `{"type": "estop"}` (same as `POST /estop`, for the lowest latency from a UI).

## Safety behavior of the server
- While connected to hardware, the server sets the board watchdog (`wd_ms`) and pings it. If the server dies, the board aborts any pending pulse and holds baseline. The `wd_ms` value is set on the bench.
- Clients disconnecting (browser tab closed) changes nothing on the board.
- `bumpem estop` from a terminal goes through the server while one is running, because the server holds the port.

## Examples
```sh
curl -X POST localhost:8000/api/v1/connect -H 'content-type: application/json' -d '{"port":"sim"}'
curl -X POST localhost:8000/api/v1/arm
curl -X POST localhost:8000/api/v1/pulse -H 'content-type: application/json' \
     -d '{"amps":{"A":95},"rise_ms":50,"dur_ms":600,"fall_ms":0}'
```
```matlab
opts = weboptions('MediaType', 'application/json');
webwrite('http://127.0.0.1:8000/api/v1/pulse', struct('amps', struct('A', 95), ...
         'rise_ms', 50, 'dur_ms', 600, 'fall_ms', 0), opts);
```

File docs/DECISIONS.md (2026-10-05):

# Decisions

Append-only. Format: `## D<n> — <date> — <title>` / Decision / Reason / Alternatives.

## D1 — 2026-09-23 — Keep legacy untouched
Decision: `legacy/` is read-only reference. Firmware work starts from a verbatim copy in `firmware/src/main.ino`.
Reason: thesis results were produced with this code; need a known-good baseline.

## D2 — 2026-09-23 — PlatformIO replaces Arduino IDE
Decision: build/flash via `pio` CLI (`firmware/platformio.ini`, `upload_protocol = teensy-cli`).
Reason: reproducible, scriptable, pinned library deps, no GUI.
Alternatives: arduino-cli (fine, less dependency pinning).

## D3 — 2026-09-23 — Python package is the API; UI is a client
Decision: all device/gait/experiment logic in `bumpem/`. UI and CLI only call it.
Reason: same code path for UI, headless scripts and tests.

## D4 — 2026-09-23 — UI stack (proposed, not final)
Decision: PySide6 + pyqtgraph.
Reason: real-time force plots at ~100 Hz × 4 channels; native desktop, offline lab PC.
Alternatives: NiceGUI (web, easier layout, weaker real-time plotting).

## D5 — 2026-09-23 — Pin firmware platform and libraries
Decision: `platformio.ini` pins teensy@6.0.0, Adafruit MCP4728@1.0.10, Adafruit BusIO@1.17.4 (versions from the first successful build).
Reason: D2 promised pinned deps; unpinned `lib_deps` would pull whatever is latest.
Note: the versions used for the thesis are unknown (Arduino IDE install on the lab PC). Check there if behavior differs.

## D6 — 2026-09-29 — Firmware v1: generic pulse API, host owns semantics
Decision: new `firmware/src/main.ino` implements protocol v1 (`docs/PROTOCOL.md`): per-channel trapezoid `PULSE` (amplitude relative to baseline, delay/rise/dur/fall), runtime `SET/GET` parameters, `ARM`/`RELEASE`/`ESTOP`/`ABORT`, typed lines, ack per command, firmware force clamp, over-force fault, optional watchdog, non-blocking fixed-rate loop. Angles, gait/PTO, sequences stay on the host.
Reason: one board API usable by any front end; porting to another board only needs the pin/DAC/ADC layer. Terms follow `docs/knowledge/perturbation_definitions.md` (duration = start→end incl. ramps; amplitude relative to baseline).
Defaults reproduce v0 control (gains, kff 7.5, 10 ms, no filter). Deliberate differences from v0: boots DISARMED (send `ARM`); channel D disabled by default; `stop` is recoverable (`ARM`); commands work mid-pulse; one `fastWrite` I²C transaction at 400 kHz instead of four at 100 kHz.
v0 remains buildable from `legacy/` via `firmware/legacy/platformio.ini` (`scripts/flash.sh legacy`) as the reference.
Alternatives: keep v0 letter commands and add parameters (no general API); angle-aware firmware (couples board to geometry).

## D7 — 2026-09-29 — Baseline window and balance recovery
Decision: baseline force/SD = first 3 s of the trial (fixed). Balance recovery is decided by the lab's existing algorithm (gait prediction + whole-body angular momentum), plugged into the host as an external detector; bumpem does not implement its own.
Reason: project lead's choice; the recovery algorithm already exists and is validated in the lab.
Consequence: recovery needs whole-body kinematics (Vicon marker/segment data), not only force plates. `bumpem/vicon.py` must stream markers too.
Alternatives: rolling pre-pulse baseline; stride-time placeholder criterion (dropped).

## D8 — 2026-09-29 — Recovery hook and stand-in
Decision: `bumpem/recovery.py` defines `RecoveryDetector` (`start(t)`, `update(t, frame) -> bool`). `Scheduler(recovery=...)` counts foot strikes toward the next perturbation only after `update` returns True; `recovery=None` keeps the MATLAB behavior. Stand-in `FixedWaitRecovery(wait_s)` = fixed time after the perturbation, no default value. Marked `TODO(recovery)` where the lab algorithm goes.
Reason: lets the trial loop and UI be built before the algorithm is integrated (D7).

## D9 — 2026-09-29 — UI is a web page served by a local bumpem server (replaces D4)
Decision: `bumpem serve` runs on the PC the Teensy is plugged into, owns the serial port, and exposes the HTTP/WebSocket API in `docs/API.md`. The UI is a browser page served by it (FastAPI; plain HTML/JS with vendored libraries, no Node build, works offline). Bound to 127.0.0.1 by default.
Reason: same UI on Windows/Linux/macOS; one process owns the port (no v0 port contention); closing the UI does not stop control; MATLAB and future apps use the same API.
Alternatives: PySide6 + pyqtgraph (D4: better real-time plotting, but UI and logic in one process, no API for other apps); NiceGUI (Python-only UI, more version churn).
Open: installer route (`uv` + lockfile proposed), Linux udev rule script, Vicon SDK availability per OS.

## D10 — 2026-09-29 — Server is the product; UI is a separate client in the same repo
Decision: firmware + protocol + `bumpem` package (server) form the product and stay together. The web UI lives in `ui/` and talks to the server only through `docs/API.md`, never by importing `bumpem`. Same repo for now; `ui/` can move to its own repo later without changes.
Reason: firmware, protocol and server change together (CLAUDE.md rule 4); the UI is the replaceable part. Future students can replace the UI or script the server directly. One repo keeps setup simple for a small team.
Alternatives: two repos now (two versions to keep in step, two clones for a new student).

## D11 — 2026-09-29 — Workspace split into BumpemServer and BumpemUI
Decision: the workspace `IBMS_Offenburg/` holds two folders, each shaped as a future repo: `BumpemServer/` (everything that existed: firmware, protocol, `bumpem` package, docs, tests) and `BumpemUI/` (web client). Each has its own README, CLAUDE.md, STATUS.md and DECISIONS.md. The `bumpem/ui/` PySide6 stub, the `ui` extra and the `bumpem-ui` entry point were removed (superseded by D9).
Reason: D10 in folder form; either folder can become its own git repo without moving files.
Contract: `BumpemServer/docs/API.md`. The UI records which API version it targets.

## D12 — 2026-09-29 — Recreate the on-board calibration sketch before flashing
Decision: the unknown load-cell sketch on Teensy 16922250 is recreated from its observed output (pin A1 found by jumper probe; format, 200 ms period and formulas measured) in `firmware/tools/loadcell_check/`, flashable with `scripts/flash.sh loadcell`. The board is flashed only after the project lead accepts the recreation.
Reason: Teensy flash cannot be read back; the project lead wants the sketch kept. A recreation makes flashing v1 reversible.
Alternatives: find the original source (still preferred if it turns up); use a second Teensy for development.

## D13 — 2026-10-01 — Preliminary tests with the drivers' current ESCON configuration
Decision: module C (and other modules) are tested as configured now (module C: Diagnostics passed after the Hall-GND fix). Uploading and comparing each driver's config, and re-running auto-tuning where needed, is deferred to "Before final testing" (`docs/TODO.md`).
Reason: project lead's choice; the configuration is either module-specific tuning or the untuned Stanford reference, both workable for low-force preliminary tests.
Alternatives: check/auto-tune every driver first.

## D14 — 2026-10-02 — Git holds only the code and docs in use
Decision: the repo tracks code (`bumpem/`, `firmware/src`, `firmware/platformio.ini`), tests, `scripts/`, `.md` docs, ESCON `.edc` files and one diagram, `docs/diagrams/cabling-4-modules.png` (4 modules, same cabling per module). Thesis, reference PDFs, photos, `legacy/`, `firmware/legacy/`, `firmware/tools/` and diagram sources/exports stay on disk, listed in `.gitignore`. History squashed to one commit before the first push so the PDFs (≈ 30 MB) never reach the remote.
Reason: project lead's choice: upload only what is used.
Consequence: `legacy/` (MATLAB/v0 reference for rule 5) and the thesis must be shared separately with anyone who needs them.

## D15 — 2026-10-02 — Carrier board: 2-layer PCB, generated from a netlist
Decision: replace the breadboard with `hardware/carrier/`: Teensy 4.1 and MCP4728 on female headers, one 5-way terminal per module (pin order EN, SP+, SP−, GND, F), protection on each force input (1 kΩ series, 1 MΩ pull-down, BAT85 to 3.3 V). 2 layers, through-hole, ordered from a PCB maker; the makerspace helps with ordering and soldering. KiCad files are generated (`netlist.py` → `gen_schematic.py`, `gen_carrier.py`) and checked by `build.sh` (ERC, DRC, schematic parity).
Reason: per-module terminals force the enable, setpoint and force wires to cross; single-sided would need ~10 wire jumpers. Sockets keep Teensy and DAC replaceable. Protection values keep the calibrated 0–3.3 V signal (99.9 %) and make an unplugged input read 0 N.
Alternatives: single-sided milled board with jumpers; perfboard; direct force connection without protection.
Update 2026-10-05 (b): module connectors changed to pluggable Phoenix MSTB 2,5 (board header MSTB 2,5/5-GF-5,08 1776537, cable plug MSTB 2,5/5-STF-5,08 1778014, both with screw flanges; optional coding CP-MSTB 1734634) so a module cable pops in and locks instead of 5 screws per module. Flanges make each header 35.7 mm wide → board 154 × 96 mm. Pin order unchanged (1 EN … 5 F), now left to right.
Update 2026-10-05: makerspace review → all corners 45° (no 90° bends), ground fill 0.5 mm from other copper (no solder mask there), separate top/bottom PDFs. Their process has no solder mask / silkscreen; plating of holes and vias still to confirm.
Update 2026-10-02 (b): module D confirmed back; board label updated.
Update 2026-10-02: force tracks rerouted under the Teensy and past its end (were 0.37 mm from unused socket pins; now ≥ 1.39 mm from any other pad); all other gaps ≥ 0.74 mm. Module D treated as active (repaired before ordering); its direction stays unlabelled until confirmed.

## D16 — 2026-10-02 — Perturbation angle: Vicon axes, vector split over neighbouring cables
Decision: the API takes a pull direction in Vicon axes seen from above (0 front, +90 left, −90 right, 180 back; normalised to (−180, 180]) and a resultant amplitude above baseline. Modules sit at A +90, B 0, C −90, D 180 (D back confirmed by the project lead). Between two neighbouring modules the amplitude is split as a vector (cos / sin of the angle past the first); on a module's axis that module alone pulls. A module is usable when its channel is on (`ch_X = 1`); other angles are refused (422). Implemented in `bumpem/geometry.py`, used by `POST /api/v1/perturbation` and `bumpem perturb`.
Reason: project lead's choice of convention (Vicon axes); the split reproduces the legacy diagonals (`legacy/Arduino_Script.ino:82`, force × 1/√2 per cable).
Assumptions: horizontal cables at right angles, attached at one point. With B missing, baseline tension leaves a constant pull of `baseline_n` towards D.
Alternatives: clockwise 0–360 convention (the lab's verbal description of the setup); per-module amplitudes only (already available as `POST /pulse`).

## D17 — 2026-10-05 — The server serves the browser UI; websockets is a server dependency
Decision: `bumpem serve` mounts `../BumpemUI/web` at `/ui/` (`--ui PATH`), `/` redirects there (BumpemUI U2). The `server` extra now includes `websockets`: plain uvicorn rejects WebSocket requests (404, "No supported WebSocket library"), so `/api/v1/stream` never worked outside the test client.
Reason: one URL, no CORS; the live stream is required by the UI.
Consequence: reinstall the extras once: `pip install -e ".[server,dev]"`.

## D18 — 2026-10-05 — The server sets the channels to the mounted modules at connect
Decision: `bumpem serve --modules ACD` (default `ACD`) switches ch_A..ch_D at connect: listed modules on, others off (only while DISARMED). `--modules ""` keeps the firmware defaults (A, B, C on, D off).
Reason: the firmware's power-up defaults date from when D was out of service; on the real board the UI showed the front (B, not installed) reachable and the back (D, installed) refused, so a back pull reached only A. Fixing it in the server needs no re-flash and is one option to change when B is mounted.
Alternatives: change the firmware defaults (PROTOCOL.md + re-flash); tick channels in the UI after every power-up.

## D19 — 2026-10-05 — Testing and production modes
Decision: `bumpem serve --testing` / `--production` (default). Testing: `POST /api/v1/test/pull` does one open-loop pull on one module (save params → gains 0, kff 2, baseline 0, cap = force, arm_ms 0, only that module → ARM → PULSE → RELEASE 0 → restore params); arm / pulse / perturbation refused. Production: the full UI (arm with force feedback, perturbations); test pulls refused. Error code `wrong_mode` (409). UI: `/ui/testing.html` vs `/ui/`.
Reason: the project lead wants a plain "does each motor react?" check without arming or constant tension, separate from the arming / feedback workflow; mixing both on one page caused confusion.
Alternatives: one page with a test card (tried, confusing); CLI only.

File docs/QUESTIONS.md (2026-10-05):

# Questions for the previous student

For the call about the Bump'em setup. Write each answer under its question.
After the call, the answers go into the docs named in *(→ …)* and the question is marked done.

Open questions on 2026-09-30.

---

## Files to ask for
Ask them to send these if they still have them:

- [ ] The **load-cell calibration sketch** that is on the Teensy now (prints `ADC: … | Voltage: … | Force: … N`)
- [ ] The **ESCON Studio parameter files** they loaded onto the drivers (`.edc`), and any saved after auto-tuning
- [ ] **Recorded trial logs** from MATLAB (`Log_event_data_*.csv` and `Perturbation_log_*.csv`)
- [ ] Any **photos or videos of the setup when it was fully wired and working**
- [ ] The earlier **Bachelor's project** documents (who built the first version?)

---

## 1. The wiring (most urgent)

**1.1** The Teensy breadboard was found disconnected from the motors. Who disconnected it, and why? Was anything else changed at the same time?
> Answer:

**1.2** Each motor driver (ESCON) has a cable with 7 wires ending in jumper pins: a set of 4 (red, blue, purple, orange) and a set of 3 (white, black, yellow). **Which colour went to which place** on the breadboard (Teensy pin, DAC output, ground)?
> Answer (traced 2026-09-30 on one driver, see `wiring.md`): black = enable, red (female) = setpoint +, orange = setpoint −, blue = force, purple = ground, yellow + white = spares. This is module C (right). Ask: are A, B, D wired with the same colours?

**1.3** Per driver, only 5 of those 7 wires should be needed: enable, setpoint +, setpoint −, and two grounds. **What are the other 2 wires for?**
> Answer (found 2026-09-30): 2 of the 7 are spare extensions, not connected at the driver.

**1.4** There is a small board with blue parts and 3 thin wires, mounted in the aluminium frame next to each motor driver. **What is it?** (A Futek amplifier? A strain-gauge board from the Bachelor's project? Something else?)
> Answer (found 2026-09-30): it is the module's **ground distributor**: joins ESCON J5.5 + J6.7 + IAA100 GND into the white wire. Ask only: anything else on it?

**1.5** Where is the **ground distributor** (the shared ground terminal strip), and what was connected to it?
> Answer:

**1.6** Where are the **Futek IAA100 amplifiers**, and how is each one powered (24 V supply)?
> Answer:

**1.7** How was the ground between the Teensy and each driver connected?
> Answer (found 2026-09-30): J5.5 + J6.7 → frame board → white wire → breadboard. Ask: where on the breadboard did the white wire go (distributor? Teensy G?)

**1.8** The motor harnesses came pre-pinned **4 + 4**: on modules C and one other, the motor's **Hall GND (blue, motor pin 6) sits on ESCON J2 pin 4 (cable shield)** and J3 pin 5 is empty. With this wiring both drivers now show a Hall sensor error. Who made these harnesses? Did the motors run with exactly this wiring during the thesis?
> Answer: (found 2026-10-01: moving blue to J3 pin 5 cleared the error on module C)

*(→ `docs/knowledge/wiring.md`, `docs/hardware-photos/README.md`)*

---

## 2. The motor drivers (ESCON 70/10)

**2.1** Did you load the **Stanford configuration file** onto the drivers as it was, or did you change settings?
> Answer:

**2.2** In that file, **10 V on the setpoint input = 30 A** of motor current. The Teensy code assumes **3.3 V = 30 A**. Which one is true on our drivers? (If it's the Stanford file, the motors never got more than about 10 A.)
> Answer:

**2.3** Which driver belongs to which module (A left, B front, C right, D)? When was each one last **auto-tuned**?
> Answer:

**2.4** Is there a **shunt regulator** (maxon DSR 70/30) for each module, and what cut-off voltage was it set to?
> Answer (found 2026-09-30): yes, maxon 235811 on the frame. Ask: DIP setting (cut-off voltage)? Where is each 48 V supply and its on/off switch? Is there an e-stop in the 48 V circuit?

**2.5** The e-stop button: how was it wired before (which terminals on the 48 V supply)? Did one button stop all modules? Was it tested before sessions?
> Answer:

**2.6** How many **48 V supplies (RSP-2000-48)** and **24 V supplies (RS-15-24)** are there, and which module does each one feed? Who in the lab handles the mains (230 V) connections?
> Answer:

*(→ `escon/README.md`, `docs/knowledge/control.md`, `docs/knowledge/wiring.md`)*

---

## 3. Module D (the 4th motor)

**3.1** Why is module D out of service? The thesis says **mechanical damage**; the manual says **a new motor driver needs to be bought**. Which is it?
> Answer:

**3.2** ~~Which direction was D meant to pull: backwards?~~ Answered 2026-10-02: back (project lead), in `knowledge/hardware.md`.
> Answer:

*(→ `docs/knowledge/hardware.md`)*

---

## 4. Force sensors and calibration

**4.1** Which **load cell** (sensor 1–4 in the calibration table) is on which **module** (A–D)?
> Answer:

**4.2** The calibration sketch reads only **Teensy pin A1** (module B's input). Was it used for all four sensors one by one, or only for module B?
> Answer:

**4.3** The thesis gives the load cell rating as 100 kg, 1000 N and 980 N in different places. What is the correct maximum?
> Answer:

**4.4** How were the amplifiers set (DIP switches, zero and span knobs)? Were they changed after calibration?
> Answer:

*(→ `docs/knowledge/calibration.md`)*

---

## 5. The control code (Teensy)

**5.1** The code holds a pulse for **600 ms**, but the thesis says **300 ms**. Which was used for the thesis experiments?
> Answer:

**5.2** At start-up the code prints "baseline = 10 N" but actually uses **5 N**. Which baseline did you use in the trials?
> Answer:

**5.3** The feedforward term is multiplied by **7.5**. Where does that number come from (tuning, a calculation, trial and error)?
> Answer:

**5.4** The motor torque constant in the code is **0.1524**. Is that from the datasheet, or measured? (The Stanford file says 0.227.)
> Answer:

**5.5** The thesis says the **200 N limit was "enforced in the control software"**, but the code has no such limit. What was meant?
> Answer:

*(→ `docs/knowledge/control.md`, `docs/knowledge/safety.md`)*

---

## 6. Running the experiments

**6.1** During a trial, **how did you stop** the system in an emergency? (MATLAB holds the USB port, so typing `stop` in the Arduino monitor wasn't possible.)
> Answer:

**6.2** Where are the **recorded trial data** (MATLAB logs, force data), and which files belong to which participant/trial?
> Answer:

**6.3** Vicon: which **PC**, which **DataStream SDK version**, and is the IP still **192.168.10.1**? Which force plate is **left** and which is **right**?
> Answer:

**6.4** Was the treadmill (**D-Flow**) ever controlled by the scripts, or always by hand?
> Answer:

*(→ `docs/knowledge/gait_detection.md`, `docs/knowledge/experiment.md`)*

---

## 7. Anything else
**7.1** Is there anything that was known to be broken, fragile or "just worked that way" that we should know about?
> Answer:

## 7. Ropes (added 2026-10-05)
**7.1** Which rope is on the modules (material, diameter, brand)? Stanford used braided Kevlar string (build guide p. 12), the thesis does not say.
**7.2** What is the breakaway link (thesis p. 17: "mechanical breakaway cable")? Stanford: Berkley FireLine with a surgeon's knot (guide p. 18). Which line / strength here?
**7.3** When were the ropes last replaced, and are spare ropes in the lab?

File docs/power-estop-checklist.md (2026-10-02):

# Bump'em: power and e-stop checklist

**What:** bring the Bump'em power supplies back into use and set up the emergency stop.
**Who:** done by the project lead (no technician available). **No work on the 230 V side**: inspect only; anything faulty goes to the university's facilities / electrical workshop. Ask the supervisor about the electrical safety inspection (DGUV Vorschrift 3).
**Date:** ______________

The system pulls a person on the GRAIL treadmill through ropes driven by motors (one module per direction).
All supplies are currently **disconnected from the mains**. The low-voltage side (48 V / 24 V DC) is wired by us;
the 230 V side is only inspected here.

---

## 1. The power supplies
Per mounted module (2026-10-02: A left, C right, D back; B front not installed). Counts to be confirmed on site.

| Unit | Qty | Mains input (label / datasheet) | Output | Feeds |
|---|---|---|---|---|
| **Mean Well RSP-2000-48** | ___ | 200–240 VAC **12.3 A** max (label); 10 A typ. @ 230 VAC full load; inrush 50 A typ. (cold start); leakage < 2 mA @ 240 VAC | 48 V DC, 42 A, 2016 W | maxon shunt regulator 235811 → maxon ESCON 70/10 motor driver |
| **Mean Well RS-15-24** | ___ | 100–240 VAC 0.35 A (label) | 24 V DC, 0.625 A (15 W) | Futek IAA100 load-cell amplifier |

Sources: unit labels (photos in `docs/hardware-photos/`), Mean Well RSP-2000 datasheet (`docs/reference/meanwell-rsp-2000-spec.pdf`).

Expected load: motor current is limited by each driver (configured limit 30 A in the reference configuration → about 1.4 kW per module at 48 V, peak, during pulses of ≤ 1 s). Normal operation is far below that. The label maximum above is the conservative figure.

## 2. Checks
- [ ] **Mains cable** on each supply (unplugged): intact plug; RSP-2000 screw terminals **⏚ / L / N** tight, **earth connected**, terminal cover on, cable strain-relieved; RS-15-24 likewise. Faulty → university, not DIY.
- [ ] **Circuit capacity**: first test = 1 × RSP-2000-48 (12.3 A max, 50 A inrush) + RS-15-24 (0.35 A) on one wall socket or one 16 A switched strip. All modules: each RSP-2000 on its own socket/circuit.
- [ ] **A switch for the 48 V supplies** reachable from the operator position (the RSP-2000 has no power switch): the switched strip.
- [ ] **Earthing** (ask the supervisor if unsure): the RSP-2000 ⏚ goes to the shunt regulator's safety-earth terminal (pin 3). The motor drivers' signal ground is joined to a microcontroller that is USB-connected to a PC. maxon warns about potential differences between the driver supply and a PC (ESCON 70/10 hardware reference, "Hot plugging the USB interface…"). Is anything else needed?
- [ ] **Emergency stop** (section 3): low-voltage side, CN501 is isolated from the mains per the datasheet; wire it yourself with the supply unplugged.

## 3. Emergency stop: current design and question
Design from the Stanford Bump'em build guide (pp. 13–15), which this system follows:

- Mushroom e-stop with an **SPST-NO** contact block, wired to each RSP-2000's control connector **CN501 pin 7 (Remote ON-OFF)** and **pin 11 (+5V-AUX)**.
- Datasheet: **short** between pin 7 and pin 11 = **output OFF**; **open** = **output ON**. Pressing the button closes the contact → 48 V output off.
- CN501 = Hirose DF11-12DP; mating housing DF11-12DS + DF11 crimp terminals.
- One NO contact block per RSP-2000, stacked on one button.

**Known weakness:** not fail-safe. A broken wire or loose connector leaves the contact open → the supply stays **ON** and the button does nothing.
The mains, and the supply's own +5 V/+12 V auxiliary outputs, stay live after pressing.

**Open question for the supervisor:** is this acceptable under the lab's safety rules, or is a fail-safe variant required (e.g. an NC e-stop contact holding a relay, so a wire break also switches off)? Until answered: **test the e-stop before every session**.

Pressing the stop removes all rope force (intended). The treadmill has its own e-stop, which stays the primary stop for the person on it.

## 4. Sign-off
| Item | Checked by | Date | Notes |
|---|---|---|---|
| Mains cables inspected, earth connected, covers fitted | | | |
| Circuit capacity checked | | | |
| 48 V switch position | | | |
| E-stop wired (CN501 pin 7 + 11), supervisor informed | | | |
| E-stop tested (press → 48 V off, release → on) | | | |

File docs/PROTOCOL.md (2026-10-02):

# Host ↔ Teensy serial protocol

Single source of truth. `bumpem/protocol.py` must mirror this file.

## v0 — legacy (current firmware, `legacy/Arduino_Script.ino`)

Transport: Teensy USB serial (baud ignored by USB; 115200 set). Line-terminated `\n`, case-insensitive, trimmed.

### Commands (host → Teensy)
| Cmd | Action | Modules |
|---|---|---|
| `a` `b` `c` `d` | single impulse, 100 N | A / B / C / D |
| `ab` `bc` `cd` `da` | diagonal, 70.7 N each | pair |
| `stop` | enable LOW, DAC 0, **halt forever** | all |

Impulse: 50 ms ramp from 5 N → target, hold to 600 ms, then back to baseline. Blocking.
Unknown commands are silently ignored.

### Telemetry (Teensy → host)
Every loop (~10 ms + print time), one line per module:
```
<millis>,<A|B|C|D>,<target_N>,<measured_N>
```
Interleaved with free-text status lines (e.g. `Running impulse on MODULE 1 (A)...`, `Stopped.`).
Host parser: accept lines matching `^\d+,[ABCD],-?\d+\.\d+,-?\d+\.\d+$`; treat everything else as a status message.

### Known issues (fix in v1)
- No ack / no error on unknown command.
- No force clamp; `stop` is irreversible; commands ignored during impulse.
- Telemetry and status share one stream without a type prefix.

## v1 — current (`firmware/src/main.ino`)

Board-agnostic: the firmware knows channels, forces and times only. Angles, gait, PTO and
sequences live on the host. Parameter defaults reproduce v0 behavior.

Transport: USB serial, one ASCII line per message, `\n` terminated. Host→board tokens are
space-separated, case-insensitive. Board→host lines are comma-separated, first field = type.
Every command gets exactly one `A` line, in order. Any received line feeds the watchdog.

### Commands (host → board)
| Command | Allowed in | Effect |
|---|---|---|
| `INFO` | any | `I,proto=1,fw=<ver>,board=teensy41,channels=4,f_hard_max=200` |
| `GET [name]` | any | One `P,<name>,<value>` per parameter (or the one named), then ack |
| `SET <name> <value>` | no pulse pending/active | Set a parameter (table below). Range-checked |
| `ARM` | DISARMED, ESTOP | Enable drivers, ramp 0 → baseline over `arm_ms` → ARMED |
| `PULSE <id> <delay> <rise> <dur> <fall> <aA> <aB> <aC> <aD>` | ARMED, no pulse pending/active | Schedule one pulse (below) |
| `ABORT` | any | Cancel pending pulse; ramp an active one back to baseline over its `fall` |
| `RELEASE [ms]` | ARMED, FAULT | Ramp all targets to 0 over `ms` (default 1000), then disable → DISARMED |
| `ESTOP` (alias `STOP`) | any | Drivers disabled and DAC 0 immediately → ESTOP. Recover with `ARM` |
| `CLEAR` | FAULT | → ARMED |
| `STATS` | any | `I,loop_us_max=..,overruns=..,tx_drops=..,uptime_ms=..` (resets max) |
| `PING` | any | Ack only (watchdog feed) |

**Safety:** only ESTOP and RELEASE drop tension. Stop the treadmill before either (`docs/knowledge/safety.md`).

### Pulse
Times in ms, amplitudes in N **relative to baseline** (`docs/knowledge/perturbation_definitions.md`).
Target per channel, `e` = time since pulse start:
```
e < rise                : baseline + a * e/rise
rise <= e < dur - fall  : baseline + a
dur - fall <= e < dur   : baseline + a * (dur-e)/fall
```
- `delay` 0–10000: start = receipt + delay (host computes it from PTO).
- `dur` = start to end, ramps included. Requires `rise + fall <= dur <= pulse_max_ms`. `rise = fall = dur/2` is triangular.
- Rejected (`A,ERR`) if any `a < 0`, `a > 0` on a disabled channel, or `baseline + a > fmax_n`.
- v0 `a` equivalent: `PULSE 1 0 50 600 0 95 0 0 0`. v0 `ab`: amplitudes `65.71 65.71 0 0`.

### States
`DISARMED` (boot) → `ARMING` → `ARMED` ⇄ `FAULT`; `RELEASING` → `DISARMED`; any → `ESTOP`.
Boot does **not** ramp to baseline (v0 did). Send `ARM`.

### Board → host
| Line | Meaning |
|---|---|
| `T,<ms>,<state>,<pulse_id>,<tgtA>,<fA>,<dacA>,<tgtB>,<fB>,<dacB>,<tgtC>,<fC>,<dacC>,<tgtD>,<fD>,<dacD>` | Telemetry every `tel_div` loops. `f` = raw measured N, `dac` = 0–4095 (4095 = saturated). `pulse_id` 0 = none |
| `A,OK,<CMD>[,<detail>]` / `A,ERR,<CMD>,<reason>` | Ack |
| `E,<ms>,<kind>[,...]` | `PSTART,<id>` `PEND,<id>` `PABORT,<id>` `STATE,<name>` `FAULT,<ch>,<f>` `WD` |
| `I,...` / `P,<name>,<value>` | Info / parameter |

Telemetry is dropped (counted in `tx_drops`) rather than blocking the control loop when the USB buffer is full.

### Parameters (`SET`/`GET`)
Defaults = v0 firmware. † only settable when DISARMED.
| Name | Default | Range | Meaning |
|---|---|---|---|
| `loop_ms`† | 10 | 1–50 | Control period (fixed-rate; v0 was ~10 ms + overhead) |
| `kp_track` `kd_track` | 0.24, 3.5 | 0–100 | PD gains outside pulses |
| `kp_pulse` `kd_pulse` | 0.24, 3.5 | 0–100 | PD gains during a pulse. `kp = kd = 0` → open-loop |
| `kff` | 7.5 | 0–20 | Feedforward multiplier (Stanford guide: 1) |
| `rc` | 0.01905 | 0.001–0.2 | Drum radius, m |
| `kt` | 0.1524 | 0.001–10 | Torque constant |
| `i_full` | 30 | 1–100 | Current at DAC full scale (ESCON AnIn2 scaling) |
| `f_full` | 200 | 1–1000 | Force at ADC full scale |
| `baseline_n` | 5 | 0–30 | Tracking force |
| `fmax_n` | 200 | 0–200 | Target clamp (hard ceiling 200) |
| `fault_n` `fault_ms` | 195, 20 | 0–200, 1–1000 | Measured ≥ `fault_n` for `fault_ms` → abort pulse, FAULT (0 = off) |
| `filter_hz` | 0 | 0 or < 500/`loop_ms` | 2nd-order Butterworth on measured force (0 = off, v0) |
| `d_window` | 1 | 1–8 | D term over m samples: `(f - f[i-m]) / (m*loop_ms)` (Stanford: 3) |
| `arm_ms` | 2000 | 0–10000 | Arm ramp |
| `pulse_max_ms` | 1000 | 1–5000 | Longest allowed `dur` |
| `tel_div` | 1 | 0–1000 | Telemetry every n loops (0 = off) |
| `wd_ms` | 0 | 0–60000 | No line for this long → abort pulse, `E,WD` (0 = off) |
| `ch_A`..`ch_D`† | 1,1,1,0 | 0/1 | Channel enabled (default D off: it was out of service; `set ch_D 1` to use it) |
| `gain_A`..`gain_D`, `offset_A`..`offset_D` | 1, 0 | 0.5–2, −20–20 | Per-sensor calibration: `f = raw/1023*f_full*gain + offset` |

Control law (per enabled channel, every loop), unchanged from v0 with defaults:
```
ff    = filter(f)                       # identity when filter_hz = 0
d     = (ff - ff[i-m]) / (m*loop_ms)
ides  = kp*(tgt - ff) - kd*d + kff*tgt*rc/kt
dac   = clamp(ides/i_full, 0, 1) * 4095
```

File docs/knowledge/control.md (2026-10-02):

# Force control (as implemented)

Source of truth: `legacy/Arduino_Script.ino`. Thesis §2.6 and Appendix pseudocode match structurally.

## Parameters
| Name | Value | Line |
|---|---|---|
| Loop period `T` | 10 ms (`delay(T)`, not fixed-rate) | 22, 224 |
| `Pgain` | 0.24 | 25 |
| `Dgain` | 3.5 | 26 |
| `feedforwardGain` | 7.5 | 29 |
| `rc` (drum radius) | 0.01905 m | 32 |
| `kt` | 0.1524 | 33 |
| Baseline | 5.0 N | 36 |
| Impulse force | 100 N | 77 |
| Impulse duration | **600 ms** (thesis §4.3 says 300 ms) | 78 |
| Impulse ramp | 50 ms linear from baseline | 335 |
| Diagonal scale | 0.7071 per module | 83 |
| Startup ramp | 0 → baseline over 2000 ms | setup() |

## Law (per module, every loop)
```
f      = raw/1023 * 200                 # N
ef     = fdes - f
d      = (f - f_prev) / T               # T in ms → N/ms (Dgain is tuned for this unit)
ipd    = Pgain*ef - Dgain*d
iffwd  = feedforwardGain * fdes * rc/kt
ides   = ipd + iffwd
U      = clamp(ides * 3.3/30, 0, 3.3)   # V to DAC; implies 3.3 V ↔ 30 (ESCON AnIn2 scaling — verify in escon/)
DAC    = int(4095/3.3 * U)
```

## Derived observation (verify on hardware)
Feedforward alone reaches DAC full scale (`ides = 30`) at `fdes = 30*kt/(7.5*rc) ≈ 32 N`.
So at 100 N the command is **saturated** for the whole impulse. Peak force is then set by the ESCON
current limit / AnIn2 scaling and the mechanics, not by the PD loop. This is consistent with the
module-to-module peak differences in the thesis (Table 2: 81.7–114.9 N).

## Behavioral facts relevant to the host
- Impulses are **blocking** (`while` loop, 600 ms). Serial commands are not read during an impulse.
- Telemetry is printed every loop for all 4 modules (see `docs/PROTOCOL.md`).
- Module D is driven to baseline even though it is out of service.

## ESCON setpoint scaling (added 2026-09-30)
The Stanford ESCON configuration that manual §4.3.1 says to load (`escon/stanford/`, decoded in `escon/README.md`) maps AnIN2 **0–10 V → 0–30 A (3 A/V)**.
The firmware's `U = ides * 3.3/30` assumes **3.3 V → 30 A**. If the IBMS drivers use the Stanford file, the DAC's full scale 3.3 V commands **9.9 A**.
Consistency check (not proof): 9.9 A × kt / rc gives 79 N with the firmware's kt = 0.1524, or 118 N with the config's 226.8 mNm/A, which brackets the thesis 100 N peaks (81.7–114.9 N, `results.md`).
So peak force may be set by this 9.9 A ceiling. Confirm by reading each driver's configuration with ESCON Studio before changing `i_full` or `kff`.
**Confirmed 2026-10-01 on module A's driver** (`escon/moduleA_left_2026-10-01.edc`): set value 0–10 V → 0–30 A. So the current at DAC full scale (3.3 V) is **9.9 A**: firmware `i_full` should be **9.9**, not 30 (or the ESCON scaling changed instead). Decide after the first test; changing it raises the commanded current about 3× for the same force target.

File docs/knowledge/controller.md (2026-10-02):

## Controller
In this section we outline the general processes we use to build the open-loop and
closed-loop controllers used in the associated ICRA 2020 manuscript.
Controller hardware
We did not provide a recommended controller as there are a large number of options to choose
from, ranging from large real-time machines, to inexpensive microcontrollers. Two key functional
components to consider when choosing a controller are:
1) Input and output ports
Our proposed setup is configured for analog communication to and from the controller.
Your chosen controller should be able to handle the following port requirements
depending on your chosen configuration. Multiply the numbers with the number of
modules you have if you are using a shared controller across modules.
Configuration Analog in Analog out
Open-loop 0 2 (or 1 Analog, 1 Digital):
Motor command & Motor enable
Closed-loop 1: Strain gauge signal 2 (or 1 Analog, 1 Digital):
Motor command & Motor enable

Optional Encoder Additional 1: Encoder signal Additional 0
2) Clock speed
Faster clock speeds will allow faster control loop update rates.
The results shown were collected using a Speedgoat Performance real-time target machine with
IO106 (Analog in) and IO111 (Analog out) boards and running the control loop at 1000Hz. The
newer Teensy boards (3.5 onwards) boast impressive clock speeds that should allow similar
loop rates, depending on the complexity of your code. We have not verified the Teensy
controllers work in this application, but their data sheets indicate they could be a good option to
try.

34

Control architecture
The basic control architectures are shown below: A corresponds to open-loop control and
B corresponds to closed-loop proportional-derivative (PD) control.

Controller

Where fdes

is the desired force, rc

is the radius of the reel drum, kt

is the motor torque constant,

ides
is the desired current, i is the actual current sent to the motor, fout

is the force output from the

Bump’em module, i
ffwd
is the feed-forward current contribution to the desired current, fmeas
is the

force measured from the strain gauge force sensor, ef

is the error in the force, and ipd
is the PD

controller contribution to the desired current.
The left half of the both architectures contain the features that the controller code is in charge of,
and will be the focus of this section. The setup of components in the right half have been
described in previous sections.
Each of the variables in the controller half of the control architecture diagram can be modified if
needed. The following are notes on each of the variables fdes
, rc
, kt, fmeas
, and the PD controller,

and an additional note on the motor driver current regulator gains.
1) Reel drum radius rc
The reel drum design file provided has a radius rc of 0.75in.
Adjusting this will change the mechanical advantage of the motor transmission.
To change the radius, you will need to modify the reel drum CAD file in CAD -> 1) Motor
Unit -> Reel drum. Make sure to check the mating with other parts after the modification.

35

2) Desired force fdes
The system can comfortably apply perturbations of up to 200N for both open-loop and
closed-loop configurations. The commanded force can also be varied over time to apply
arbitrary perturbation force trajectories. The following figures show the corresponding
performances reported in the ICRA 2020 paper.

3) Motor torque constant kt
The torque constant of the motor, kt, is not exactly as defined in the maxon spec sheet
and therefore must be experimentally determined. We found kt_experimental = 0.89*kt_nominal.
You should be able to use the same value. However, you can also check the value for

36

your own motor if there are discrepancies in your system performance that you suspect
could be caused by an inaccurate motor constant.
To check this, we attached the rope to a treadmill handrail and performed several
step-response tests using open-loop control of the motor. If you have a force sensor, or
use our DIY force sensor, you can do this experiment yourself. Essentially you are
looking for the measured steady-state force (pulls of approx 1-2s should suffice) for a
given current command.
The reason for the discrepancy between kt_experimental and kt_nominal

is that the kt_nominal
reported by maxon is a result of a linearized torque constant calculated for the motor for
its ideal operating conditions. We use the motor near stall, which is quite far from its
peak efficiency/power region. Although kt for a brushed motor is fairly constant for
different current inputs/rotational speeds, the same is not true for brushless motors and
as a result, the linearized value provided by maxon does not hold during our
applications. Another point to note is that although the motor specifications state a stall
current of 56.9A, this is again an extrapolated value based on the motor’s performance
closer to the optimal efficiency/power region. In fact magnetic saturation of the motor
begins to set in around 30 A, and therefore buying a different motor driver with higher
current output will not increase the available torque from the motor.
4) Measured force fmeas
Both the force sensor and motor encoder signals (if used) are filtered with a 2nd order
Butterworth filter with a cutoff frequency of 60 Hz prior to being used in any calculation.
You can tune the order and frequency to achieve the best performance for your system.
It is likely that you might have a different ideal filter frequency if your data sampling rate
is far from the 1000Hz we used.
5) PD gains (Only for closed-loop configuration)
The parameter tuning procedure for the closed-loop step response gains is as follows:
Do a series of step-response perturbations on a standing individual. Start with open-loop
(P and D = 0), then increase P until the step response overshoots by 10%, then increase
D until the overshoot is back under 10%, repeat until there are growing oscillations
(instability) in the force output. Once the controller is unstable, reduce the P and D gains
to the best values prior to instability. Test pulls should be the maximum duration you
anticipate using (we used approximately 500ms step responses), as any instability will
grow with time and testing with the longest step input duration improves likelihood of
stability for all pulls. We achieved sufficient performance using the same gains (Kp =
0.21, Kd = 3) for each force step command magnitude, however for more accurate
tracking, one could tune the PD controller for each force magnitude.
6) The current regulator gains of the motor-driver
We selected current regulator gains that worked well for all of the scenarios in which we
tested Bump’em. All recommended parameters listed here were used in conjunction with
the motor driver parameters as setup in the previous section. However, if your system

37

happens to have very different system dynamics (e.g. much longer rope lengths), or you
want to build Bump’em for a very specific experiment and want to try to account for
force-level system dynamics, you can re-tune the current regulator. The previous section
describes how to change the input values. This can be particularly valuable for the
open-loop system that doesn’t have the higher level PD control loop that the force
sensor enables. For the closed-loop system, the current regulator gains and the PD
gains will work in a cascaded control scheme and altering the current-regulator gains will
likely result in needing to retune the force-level PD gains.
Basic controller: Applying a perturbation
The following is some pseudo code for applying a basic step response perturbation.
Pseudo code for basic open-loop control
if (perturb_now)
fdes = perturbation_force
else
fdes = 0 (Or apply low-force tracking, described in next section)
end
ides = fdes * rc
/ kt

This basic control strategy was what we used to obtain the results as presented in the ICRA
2020 paper. However, rise time performance can be improved by applying more aggressive
control schemes. An extreme example of this is a time-based bang-bang control for a
step-response. We managed to achieve 0-90% rise times in the 30-40 ms range (compared to
59ms with just the basic controller) when using a hand-tuned bang-bang controller
(approximately 25 ms maximum current in pulling direction and then 9 ms in maximum reverse
to decelerate the motor drum) but found it to be too sensitive for a general-purpose research
tool. However, if rise-time is critical for you, and you can deal with the sensitivity to changes in
system dynamics by continuously re-tuning the bang-bang controller to different scenarios, it
can be a very worthy path of exploration for the sensorless route.
Pseudo code for PD closed-loop control
filter fmeas
if (perturb_now)
fdes = perturbation_force
else
fdes = 0 (Or apply low-force tracking, described in next section)
end
ef = fdes - filtered_fmeas
derivative_ef = derivative_fdes - derivative_filtered_fmeas (or any other smoothed derivative
1
)

ipd = P gain * ef + D gain * derivative_ef
i
ffwd = fdes * rc
/ kt

38

ides = i
ffwd + ipd
ef,old = ef
1
In the ICRA 2020 work, derivative_filtered_fmeas

term was calculated using a noise-suppressing
numerical differentiation method that averages the derivative of the measured force over the
previous m time steps, we used m = 3:
Notation: Derivative_filtered_fmea at timestep i = Derivative_filtered_f
i
meas

Derivative_filtered_f
i
meas =
(1/m)*(filtered_f
i
meas - filtered_f
i - m
meas)

Described in detail in eq. 29 of Y. Q. Chen and K. L. Moore, “An optimal design of pd-type
iterative learning control with monotonic convergence,” in Proceedings of the IEEE Internatinal
Symposium on Intelligent Control, 2002, pp. 55–60.
Example feature 1: Applying low-force tracking
We apply a constant low force in between perturbations to maintain a minimal amount of slack
in the rope. For the open-loop controller, we can only tune the force. For the closed-loop
controller, we can tune both the force and the PD gains.
Tuning the force level
When a participant moves, if the tracking force is too low, the motor drum’s rotation will lag
behind the motion of the user, causing it to “bounce” against the user as they pull away. To
reduce these bounces as the user moves, increase the tracking force. The following table lists
the tracking forces that worked best for us.

Closed-loop Open-loop
Standing 3N 3N
Walking 12N 3N

We generally try to keep tracking forces as low as possible while still allowing us to achieve
acceptable slack management, since it can affect the user’s standing posture or walking gait. If
this is a big concern and you have more than one module, you can place one on either side of
the participant (for example, to the left and right) so the net force applied when both modules
apply equal tracking force (in opposite directions) sums to zero.
Tuning the PD gains (Closed-loop only)
We used different PD gains for low-force tracking than what we used for perturbations.
We tuned the gains using a similar procedure as mentioned previously. The notable
difference in the procedure is that instead of doing a step-input, we turned on low-force
tracking and had the participant stand or walk while we monitored the tracking accuracy of

39

the commanded force value, and for high-frequency oscillations (instability). The following
table lists the PD gains that worked best for us:

Closed-loop Open-loop
Standing Kp = 0.3, Kd = 1 NA
Walking Kp = 1, Kd = 1 NA

Example feature 2: Applying a virtual spring
The virtual stabilizing (or destabilizing) spring controller takes in a filtered encoder measurement
(See previous section for notes on signal filtering) to estimate the participant’s position on the
treadmill. In software, we store the encoder value when the person is at the center of the
treadmill and later subtract that from every subsequent measurement to make this the “zero
point” of the virtual spring. The person’s position is then mapped to a desired force based on a
saturated spring model:

Our spring model uses a parametrization of the spring from maximum spring length dmax and
spring force saturation fsat, such that virtual spring stiffness ks = fsat/dmax

. This parametrization is
more intuitive and easy to adjust on a per-experiment basis than selecting a spring stiffness. It
also explicitly states the value for the maximum force the controller will command (summed with
a low-force tracking value) which is helpful for safety.
Virtual spring pseudo code below:

40

if d > dmax
: fdes = fsat + flft
elseIf 0 < d < dma x

: fdes = d*ks + flft

else, fdes = flft
Where d is the measured distance, dmax

is the maximum length of the spring, fdes

is the desired

force, fsat
is the force at which the controller will saturate (summed with flft yields the maximum
allowable force), ks

is the spring constant (defined above), and flft

is the desired low-force
tracking force. If using modules pulling in opposite directions on the user, the flft term is a
constant offset for the forces pulling in opposite directions and effectively “cancels out” for the
net force felt by the user, as described in the Applying low-force tracking section.
Recording the measured force, fmeas

, from force sensor, fdes

, and d while a spring is engaged for
about 30s - 1 min as the participant moves back and forth across the range of the spring
enables you to plot the effective spring relationship (see Fig. 4 in ICRA 2020 manuscript). The
control law for the closed-loop virtual spring is the same as for any other closed loop system
(see ICRA 2020 manuscript for details) but now fdes

is a function of the participant’s position on

the treadmill, measured with the encoder, as shown above in pseudo code.
We used the same PD gains for tracking a virtual spring as for the step-input perturbations and
tracking of various force profiles in the results of the ICRA 2020 paper in an effort to show
reasonable performance with a single set of gains not tuned to a specific person or activity.
Spring rendering can be significantly improved by tuning PD gains specifically for tracking a
virtual spring.

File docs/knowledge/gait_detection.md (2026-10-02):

# Gait event detection (as implemented)

Source: `legacy/MATLAB_script.m`, thesis §4.3 + Appendix.

## Vicon
- Host `192.168.10.1:801` (`:3`). .NET DataStream SDK. StreamMode ClientPull. Axis mapping Forward/Left/Up.
- Device data: force plates 0 and 1 (GRAIL belts), all subsamples per frame.
- Signal: `Fz_total = Fz_plate0 + Fz_plate1` (sum, so any foot).

## Parameters
| Name | Value | Line | Note |
|---|---|---|---|
| `Fz_th` | 250 N | 5 | FS and TO threshold |
| `minGaitCycle` | 0.30 s | 6 | comment says 400 ms (stale) |
| `minStanceTime` | 0.15 s | 7 | comment says 200 ms (stale) |
| min time since TO | 0.1 s | 89 | hardcoded ("minSwingTime" in thesis) |

## Logic
- **FS**: not in stance, |Fz_prev| < th, |Fz| ≥ th, t − lastFS ≥ minGaitCycle, t − lastTO > 0.1 → valid FS; else `FS_NOISE`.
- **TO**: in stance, |Fz_prev| ≥ th, |Fz| < th, stance ≥ minStanceTime → valid TO; else `TO_NOISE` (stays in stance).
- Trigger on valid FS when `fsSinceLast >= fsTarget`; `fsTarget = randi([50 75])` after each perturbation.

Python port: `bumpem/gait.py` (must match this exactly; test against MATLAB logs).

## Timing (thesis Table 5, 3.3 m/s)
Stance 246.7 / 253.8 ms; stride 660 / 789 ms; onset delay 36.0 ± 4.9 ms (~14–15 % stance).

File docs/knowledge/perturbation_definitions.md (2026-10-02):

# Perturbation definitions (lab standard)

Source: provided by the project lead, 2026-09-29. Written for treadmill belt-velocity perturbations.
All quantities are measured from the recorded signal, not commanded.

## Cable-force mapping (Bump'em, docs/DECISIONS.md D7)
Velocity → force per module (and resultant along the commanded angle). Distance → impulse ∫(F − F_baseline) dt [N·s].
- **Baseline force:** mean measured force over the **first 3 s of the trial** (fixed reference, not rolling). ± 2 SD thresholds use the SD of that window.
- **Balance recovery** (when the next random interval starts) is **not** defined here: it comes from the lab's existing algorithm (gait prediction + whole-body angular momentum). The host calls it through a plug-in interface; see STATUS.md.

| Term | Definition |
|---|---|
| Baseline velocity | Mean belt velocity during a pre-perturbation reference period (e.g., first 3 s). |
| Perturbation temporal offset (PTO) | Time from a reference event (e.g., heel strike) to perturbation start, in seconds or % of stance. |
| Perturbation start | When belt velocity leaves baseline ± 2 SD. |
| Acceleration phase one duration | Time from perturbation start to peak velocity. |
| Peak velocity | When belt acceleration returns to zero and velocity is within ± 2 SD of its maximum. |
| Perturbation duration | Time from perturbation start to end. |
| Perturbation end | Same threshold as start (baseline ± 2 SD), found by analyzing the trial in reverse. |
| Acceleration phase two duration | Time from the end of the perturbation-velocity plateau to perturbation end. The plateau end is found in reverse, where acceleration is zero and velocity is within perturbation velocity ± 2 SD of baseline. |
| Perturbation velocity | Mean belt velocity during the plateau. For triangular perturbations it is roughly the peak velocity. |
| Perturbation distance | Integral of belt velocity during the perturbation minus the integral of baseline velocity over the same time. Positive for slips, negative for trips. |
| Velocity amplitude | Perturbation velocity minus baseline velocity. |

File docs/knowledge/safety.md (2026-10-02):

# Safety

Sources: thesis §2.10; manual "Safety Considerations", §6.1 step 8; `legacy/Arduino_Script.ino`.

## Claimed
- 200 N max force "enforced in the control software" (thesis §2.10).
- Global `stop` command (thesis §2.10, manual).
- GRAIL treadmill e-stop in reach; overhead fall-arrest harness; breakaway cable.
- Shutdown order: treadmill fully stopped **before** stopping control (loss of tension = risk).
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

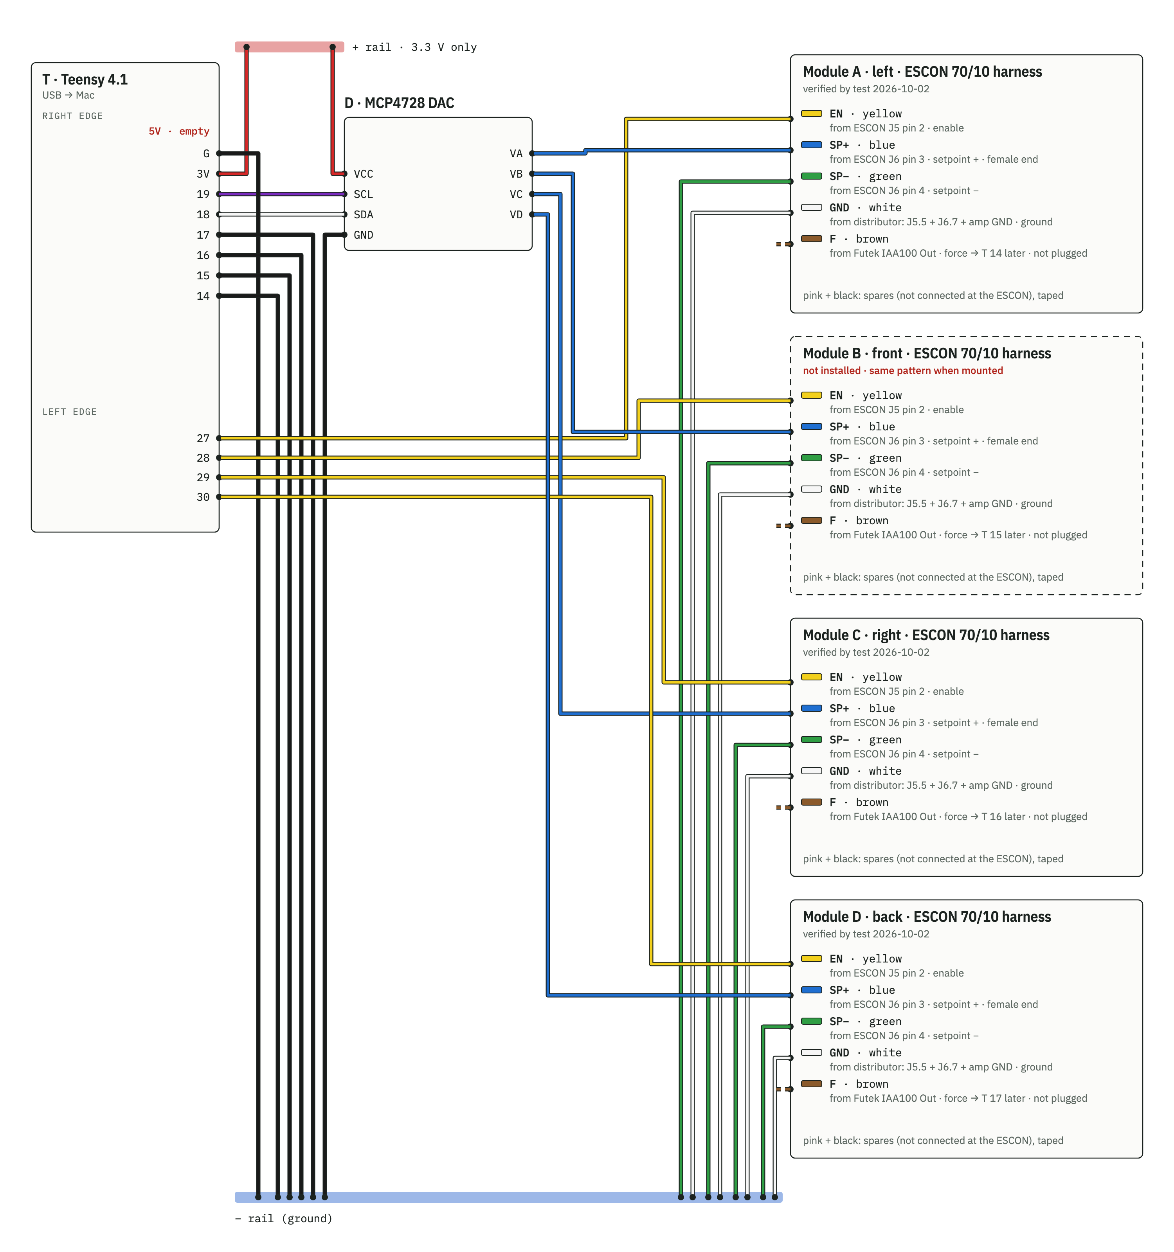
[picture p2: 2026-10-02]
docs/diagrams/cabling-4-modules.png

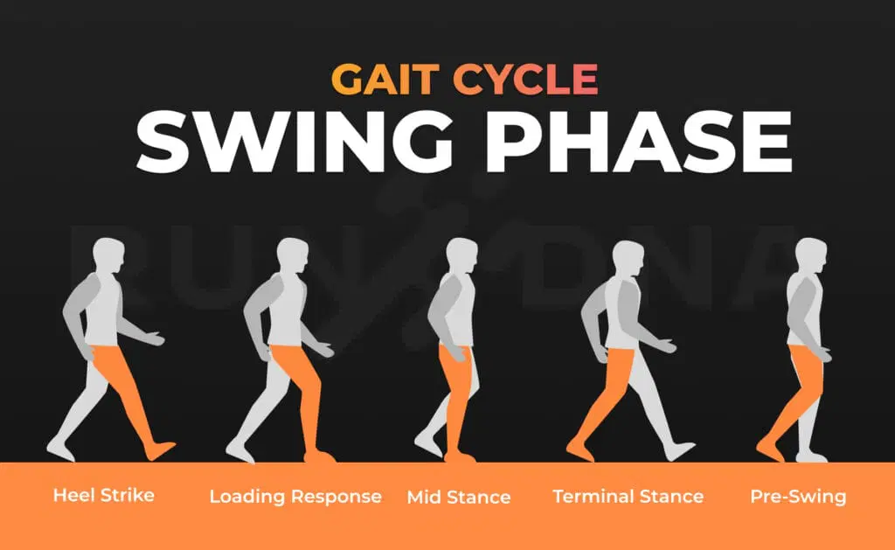
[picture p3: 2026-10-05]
docs/knowledge/SWING-Phase-1024x629.webp

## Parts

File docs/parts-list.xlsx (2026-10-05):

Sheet: Parts
Bump'em parts list (everything except motor, encoder, 48 V and 24 V supplies)
Prices looked up 2026-10-05 (web search); check before ordering. Price status: found = shop price, estimate = range given, to check = no price yet (counted as 0).
Number of towers (modules): |  | 1 | <- change this; 'tower' lines are multiplied by it
Group | Item | Exact model / part no. | Qty | Per | Unit price (EUR) | Price status | Price note (shop, VAT) | Buy / info link | Line total (EUR)
Drive electronics | Motor driver | maxon ESCON 70/10, 422969 | 1 | tower | 417.67 | found | maxon online shop, excl. VAT, qty 1-4 | https://www.maxongroup.com/maxon/view/product/control/4-Q-Servokontroller/422969
Drive electronics | Brake chopper (shunt regulator) | maxon DSR 70/30, 235811 | 1 | tower | 372.94 | found | maxon online shop, excl. VAT | https://www.maxongroup.pt/maxon/view/product/accessory/chopper/235811
Drive electronics | AC power cord for the 48 V supply | fitted by the electrician | 1 | tower |  | to check
Drive electronics | E-stop connector for CN501 | Hirose DF11-12DS housing + DF11 crimp terminals | 1 | tower |  | to check
Drive electronics | Ring terminals (supply +V / -V / earth) | for 14 AWG | 3 | tower |  | to check
Drive electronics | Power cable chopper -> ESCON J1 (m) | 14 AWG, 2-wire | 1 | tower |  | to check
Force sensing | Load cell | DYMH-103, 100 kg | 1 | tower | 100.00 | estimate | USD 60-130 (AliExpress / eBay), no EUR price found | https://www.daysensor.com/dymh-103/
Force sensing | Load-cell amplifier | Futek IAA100 (FSH03863) | 1 | tower | 871.00 | found | Elkome (EU) | https://shop.elkome.com/en/iaa100-fsh03863-load-cell-amplifier
Force sensing | Ground distributor | small screw terminal strip | 1 | tower |  | to check
Force sensing | Signal cable to the control board (m) | multi-core, 7 wires | 3 | tower |  | to check
Mechanics (Stanford guide p. 11-13) | 3D-printed motor mount, reel drum, drum cover | PLA; drum 8 shells, >= 70 % infill | 1 | tower |  | to check | printed in-house (filament below)
Mechanics (Stanford guide p. 11-13) | Socket bolts #6-32 x 1/2 in |  | 3 | tower |  | to check | see Stanford BOM | https://biomechatronics.stanford.edu/bump-em
Mechanics (Stanford guide p. 11-13) | Washers #6 |  | 3 | tower |  | to check | see Stanford BOM | https://biomechatronics.stanford.edu/bump-em
Mechanics (Stanford guide p. 11-13) | Flanged shaft collar |  | 1 | tower |  | to check | see Stanford BOM | https://biomechatronics.stanford.edu/bump-em
Mechanics (Stanford guide p. 11-13) | Socket bolts M5 x 12 mm |  | 3 | tower |  | to check
Mechanics (Stanford guide p. 11-13) | Washers M5 |  | 9 | tower |  | to check
Mechanics (Stanford guide p. 11-13) | Spider shaft coupler set | 10 mm hub + 3/8 in hub + spider | 1 | tower |  | to check | see Stanford BOM | https://biomechatronics.stanford.edu/bump-em
Mechanics (Stanford guide p. 11-13) | Flanged bearings |  | 2 | tower |  | to check | see Stanford BOM | https://biomechatronics.stanford.edu/bump-em
Mechanics (Stanford guide p. 11-13) | Linear shaft 3/8 in x 3 in |  | 1 | tower |  | to check | see Stanford BOM | https://biomechatronics.stanford.edu/bump-em
Mechanics (Stanford guide p. 11-13) | Eyebolt + 1/4 in-20 nut |  | 1 | tower |  | to check | see Stanford BOM | https://biomechatronics.stanford.edu/bump-em
Mechanics (Stanford guide p. 11-13) | Rope (m) | braided Kevlar or Dyneema, >= ~2 kN, diameter to match eyebolt | 4 | tower |  | to check
Control (once) | Microcontroller | Teensy 4.1 | 1 | system | 37.49 | found | Antratek, incl. VAT | https://www.antratek.de/teensy-4-1
Control (once) | Pin headers for the Teensy | 2.54 mm male, 2 x 24 | 1 | system |  | to check
Control (once) | DAC | Adafruit MCP4728 (product 4470) | 1 | system | 13.00 | found | Opencircuit | https://opencircuit.shop/product/adafruit-mcp4728-quad-dac-with-eeprom
Control (once) | Carrier PCB | hardware/carrier, made at the makerspace | 1 | system |  | to check
Control (once) | Female header 1 x 24, 2.54 mm, 8.5 mm tall | Teensy socket | 2 | system |  | to check
Control (once) | Female header 1 x 6, 2.54 mm | DAC socket | 2 | system |  | to check
Control (once) | Board header, pluggable, 5-way, threaded flange | Phoenix Contact MSTB 2,5/5-GF-5,08, 1776537 | 4 | system |  | to check | order no. from the KiCad footprint description; search 1776537 at phoenixcontact.com
Control (once) | Cable plug, 5-way, screw flange | Phoenix Contact MSTB 2,5/5-STF-5,08, 1778014 | 4 | system |  | to check |  | https://www.phoenixcontact.com/en-us/products/pcb-plug-mstb-25-5-stf-508-1778014
Control (once) | Coding profile (optional, keys each socket) | Phoenix Contact CP-MSTB, 1734634 (pack of 100) | 1 | system |  | to check |  | https://www.phoenixcontact.com/en-us/products/coding-element-cp-mstb-1734634
Control (once) | Resistor 1 kOhm, 0.25 W, 1 %, axial | R1-R4 | 4 | system |  | to check
Control (once) | Resistor 1 MOhm, 0.25 W, 1 %, axial | R5-R8 | 4 | system |  | to check
Control (once) | Schottky diode | BAT85, DO-35 (D1-D4) | 4 | system |  | to check
Control (once) | USB cable for the Teensy | micro-USB | 1 | system |  | to check
Safety & harness (once) | E-stop button + 1 NO contact block per 48 V supply + 24 AWG 2-wire cable | Stanford guide p. 13 | 1 | system |  | to check
Safety & harness (once) | Hip harness | Black Diamond climbing harness (Stanford) | 1 | system |  | to check
Safety & harness (once) | Breakaway line | Berkley FireLine (Stanford guide p. 18) | 1 | system |  | to check
Safety & harness (once) | PLA filament | 1 reel, for all printed parts | 1 | system |  | to check
Safety & harness (once) | Calibration weights | 6, 8, 12 kg (thesis) - the lab may have them | 1 | system |  | to check
 |  |  |  |  |  |  |  | TOTAL (priced items)
 |  |  |  |  |  |  |  | Items still without a price
 |  |  |  |  |  |  |  | Note: mixes prices incl. and excl. VAT (see column H)

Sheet: Notes
Scope: one Bump'em system; 'tower' lines are per module (set the number on the Parts sheet), 'system' lines are bought once.
Not included: motor (maxon EC 90 flat 500267, Hall sensors built in), optional encoder (Renishaw RM22), aluminium frame (80x80 profiles), 48 V supplies (Mean Well RSP-2000-48) and 24 V supplies (Mean Well RS-15-24): already in stock.
Sources: Stanford Bump'em build guide (docs/reference/stanford-bumpem-build-guide.pdf, assembly pages 11-17); BumpemServer docs/knowledge/hardware.md, wiring.md; hardware/carrier/README.md.
Stanford's full BOM spreadsheet (part numbers, prices, links for the small mechanical parts): https://biomechatronics.stanford.edu/bump-em
Mains (230 V) connection of each 48 V supply: university electrician only.
New IAA100 amplifiers: copy a working module's DIP settings, trim zero/span to 0-3.3 V = 0-200 N with known weights.

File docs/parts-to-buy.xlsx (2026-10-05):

Bump'em: parts to buy (broken tower)
Prices looked up 2026-10-05 (web search); check before ordering. 'estimate' = price range, not a shop price.
Item | Exact model / order no. | Qty | Unit price (EUR) | Price status | Price note (shop, VAT) | Buy / info link | Line total (EUR)
Motor driver | maxon ESCON 70/10, order no. 422969 | 1 | 417.67 | found | maxon online shop, excl. VAT | https://www.maxongroup.com/maxon/view/product/control/4-Q-Servokontroller/422969
Brake chopper (shunt regulator) | maxon DSR 70/30, order no. 235811 | 1 | 372.94 | found | maxon online shop, excl. VAT | https://www.maxongroup.pt/maxon/view/product/accessory/chopper/235811
Force sensor (load cell) | DYMH-103, 100 kg (same capacity as the other modules) | 1 | 100.00 | estimate | ONLY if the found 200 kg cell fails the calibration check. USD 60-130 (AliExpress / eBay) | https://www.daysensor.com/dymh-103/
 |  |  |  |  |  | TOTAL
 |  |  |  |  |  | Note: maxon prices are excl. VAT; check VAT basis of the others
Before ordering the ESCON: finish its meter tests (docs/tests/broken-tower-diagnosis.md, 2b3-2b12); only buy it if a test fails. IAA100 not needed: 4th amplifier found 2026-10-05 (paired with a 200 kg, 1.0 mV/V DYMH-103).

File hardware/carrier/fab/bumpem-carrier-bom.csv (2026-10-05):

Reference | Value | Footprint | QUANTITY
D1-D4 | BAT85 | Diode_THT:D_DO-35_SOD27_P7.62mm_Horizontal | 4
J1 | Module A | Connector_Phoenix_MSTB:PhoenixContact_MSTB_2,5_5-GF-5,08_1x05_P5.08mm_Horizontal_ThreadedFlange | 1
J2 | Module B | Connector_Phoenix_MSTB:PhoenixContact_MSTB_2,5_5-GF-5,08_1x05_P5.08mm_Horizontal_ThreadedFlange | 1
J3 | Module C | Connector_Phoenix_MSTB:PhoenixContact_MSTB_2,5_5-GF-5,08_1x05_P5.08mm_Horizontal_ThreadedFlange | 1
J4 | Module D | Connector_Phoenix_MSTB:PhoenixContact_MSTB_2,5_5-GF-5,08_1x05_P5.08mm_Horizontal_ThreadedFlange | 1
R1-R4 | 1k | Resistor_THT:R_Axial_DIN0207_L6.3mm_D2.5mm_P10.16mm_Horizontal | 4
R5-R8 | 1M | Resistor_THT:R_Axial_DIN0207_L6.3mm_D2.5mm_P7.62mm_Horizontal | 4
U1 | Teensy 4.1 | bumpem-carrier:Teensy41_Socket | 1
U2 | MCP4728 (Adafruit 4470) | bumpem-carrier:Adafruit_MCP4728_Socket | 1

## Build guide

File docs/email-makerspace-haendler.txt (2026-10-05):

An: jobs4makerspace@hs-offenburg.de
Betreff: AW: Anfrage: Prüfung und Fertigung einer Platine (KiCad) – aktualisiertes Design

Anhänge (aus BumpemServer/hardware/carrier/fab/):
  bumpem-carrier-top.pdf
  bumpem-carrier-bottom.pdf
  bumpem-carrier-schematic.pdf
  bumpem-carrier-kicad.zip
  bumpem-carrier-gerbers.zip

----------------------------------------------------------------------

Hallo nochmal, Herr Händler,

ich melde mich noch einmal kurz wegen der Platine, da ich das Design noch etwas angepasst habe.

Mir ist aufgefallen, dass der Versuchsaufbau voraussichtlich öfter umgestellt bzw. transportiert wird. Deshalb habe ich die festen Schraubklemmen durch steckbare Anschlüsse ersetzt (Phoenix Contact MSTB 2,5, Rastermaß 5,08 mm). Auf der Platine sitzt jeweils eine Stiftleiste (MSTB 2,5/5-GF-5,08), an jedem Motormodul-Kabel ein Stecker (MSTB 2,5/5-STF-5,08). Die Kabel werden einmal im Stecker verschraubt und können danach einfach abgezogen und wieder eingesteckt werden. Beide Teile haben Schraubflansche, sodass sich die Stecker im Betrieb nicht lösen.

Durch die Flansche ist die Platine etwas größer geworden: jetzt 154 × 96 mm (vorher 120 × 93,5 mm). Ist diese Größe bei Ihnen machbar?

Alle anderen Punkte sind unverändert: weiterhin nur 45°-Knicke, und die Designprüfungen in KiCad laufen fehlerfrei. Die aktualisierten Dateien finden Sie im Anhang.

Vielen Dank und freundliche Grüße
Lorenzo [Nachname]

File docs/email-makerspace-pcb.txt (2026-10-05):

An: jobs4makerspace@hs-offenburg.de
Betreff: Anfrage: Prüfung und Fertigung einer Platine (KiCad) für ein Forschungsprojekt

Anhänge (aus BumpemServer/hardware/carrier/):
  fab/bumpem-carrier-schematic.pdf
  fab/bumpem-carrier-layout.pdf
  fab/bumpem-carrier-bom.csv
  fab/bumpem-carrier-gerbers.zip

----------------------------------------------------------------------

Sehr geehrte Damen und Herren,

mein Name ist [Ihr Name], ich arbeite als [Studierender / wissenschaftliche Hilfskraft] im Projekt [Projektname, z. B. „Bump'em“-Perturbationssystem] bei [Betreuer/in, Fakultät].

Unser Versuchsaufbau wird derzeit über ein Steckbrett (Breadboard) gesteuert: Ein Teensy 4.1 und ein MCP4728-DAC-Modul sind mit Steckbrücken mit vier Motormodulen verbunden. Für den dauerhaften Laborbetrieb möchte ich das Steckbrett durch eine Platine ersetzen.

Da ich wenig Erfahrung mit CAD bzw. Platinenlayout habe, habe ich das Layout mithilfe von Claude (einem KI-Assistenten) in KiCad 8 erstellt. Die Designprüfungen in KiCad (ERC, DRC und Abgleich Schaltplan/Layout) laufen ohne Fehler durch. Trotzdem hätte ich gern die Einschätzung von jemandem mit Erfahrung, bevor die Platine gefertigt wird.

Kurz zur Platine:
- 120 × 93,5 mm, 2 Lagen, nur bedrahtete Bauteile (THT)
- Teensy 4.1 und DAC-Modul auf Buchsenleisten (steckbar)
- 4 Schraubklemmen (5-polig, Rastermaß 5,08 mm), eine pro Motormodul
- Schutzbeschaltung der Kraftsensor-Eingänge (Widerstände und Schottky-Dioden)
- Leiterbahnbreite 0,5 mm (3,3 V: 0,8 mm), kleinster Abstand zwischen Netzen 0,74 mm, kleinste Bohrung 0,8 mm (Vias 0,8/1,4 mm), Massefläche auf beiden Lagen

Meine Fragen:
1. Könnten Sie das Design einmal prüfen, ob es grundsätzlich sinnvoll und fertigungsgerecht ist?
2. Ist diese Platine bei Ihnen im Makerspace herstellbar (2 Lagen mit Durchkontaktierungen)? Falls nicht: Würden Sie eher eine Bestellung bei einem Leiterplattenhersteller empfehlen, oder gibt es Anpassungen (z. B. einlagig), die eine Fertigung bei Ihnen ermöglichen würden?
3. Wäre es möglich, die Bestückung bzw. das Löten bei Ihnen durchzuführen, gern auch mit Unterstützung oder Einweisung?

Im Anhang finden Sie:
- den Schaltplan (PDF)
- das Layout (PDF)
- die Stückliste (CSV)
- die Gerber- und Bohrdateien (ZIP)
- auf Wunsch auch das vollständige KiCad-Projekt

Gern komme ich auch persönlich vorbei, um das Projekt kurz vorzustellen.

Vielen Dank im Voraus und freundliche Grüße
[Ihr Name]
[Studiengang / Projekt, Betreuer/in]
[E-Mail, Telefon]

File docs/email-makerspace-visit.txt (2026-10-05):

An: jobs4makerspace@hs-offenburg.de
Betreff: AW: Anfrage: Prüfung und Fertigung einer Platine (KiCad) für ein Forschungsprojekt

Anhänge (aus BumpemServer/hardware/carrier/fab/):
  bumpem-carrier-top.pdf
  bumpem-carrier-bottom.pdf
  bumpem-carrier-schematic.pdf
  bumpem-carrier-kicad.zip
  bumpem-carrier-gerbers.zip

----------------------------------------------------------------------

Hallo [Name],

vielen Dank für Ihre schnelle Rückmeldung und das Angebot. Eine Platine ohne Lötstoppmaske und Bestückungsdruck ist für unseren Prototyp völlig in Ordnung.

Ich komme sehr gern im Makerspace vorbei, um das Design gemeinsam durchzugehen. Wann würde es Ihnen passen? Ich bin von Montag bis Donnerstag jeweils von 9:30 bis 17:00 Uhr verfügbar, jeder dieser Tage passt mir gut.

Ihren Hinweis zu den 90°-Biegungen habe ich bereits umgesetzt: Alle Leiterbahnen haben jetzt nur noch 45°-Knicke, die Designprüfungen laufen weiterhin fehlerfrei. Im Anhang finden Sie die Ober- und Unterseite jetzt als getrennte PDFs (die Unterseite gespiegelt, also von unten gesehen), den Schaltplan, die Gerber-Dateien und das komplette KiCad-Projekt.

Zwei Fragen, damit ich mich auf den Termin vorbereiten kann:
1. Können Sie Durchkontaktierungen (Vias) und durchkontaktierte Bohrungen herstellen? Die Platine ist zweilagig, und einige Leiterbahnen auf der Oberseite enden an den Pads der Buchsenleisten, die man von oben nicht löten kann.
2. Gibt es Mindestwerte für Leiterbahnbreite, Abstände und Bohrdurchmesser, die ich einhalten sollte? Aktuell: Leiterbahnen 0,5 mm, kleinster Abstand 0,74 mm, kleinste Bohrung 0,8 mm.

Da es keinen Bestückungsdruck gibt, würde ich die Beschriftung der Anschlüsse gern mit Ihnen besprechen (z. B. Text in der Kupferlage oder ein ausgedrucktes Etikett).

Vielen Dank und freundliche Grüße
Lorenzo [Nachname]
[Studiengang / Projekt, Betreuer/in]
[Telefon]

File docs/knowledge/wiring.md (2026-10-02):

# Wiring: one Teensy 4.1 + one MCP4728 → four modules

Sources: manual p. 2–3 (§4.2 table); thesis Fig. 7 (one module); `firmware/src/main.ino:27-31` (pin ↔ module); ESCON 70/10 hardware reference Tables 3-17, 3-19 (J5/J6 pins, `escon/`).
Diagram: `docs/diagrams/cabling-4-modules.png`.

## Shared (once)
| From | To | Note |
|---|---|---|
| Teensy **3V** (right edge, 3rd from top) | DAC **VCC** | Never the **5V** pin (top right): leave 5V unconnected |
| Teensy **G** | DAC **GND** | |
| Teensy **19** | DAC **SCL** | |
| Teensy **18** | DAC **SDA** | |
| Teensy **G** | Ground distributor | Common ground for everything below |
| DAC LDAC, RDY | not connected | |
| Teensy USB | lab PC | Powers Teensy + DAC |

## Per module
| Signal | A (left) | B (front) | C (right) | D (back) |
|---|---|---|---|---|
| Teensy → ESCON **DigIn2** (enable, **J5 pin 2**) | pin **27** | pin **28** | pin **29** | pin **30** |
| DAC → ESCON **AnIn2+** (setpoint, **J6 pin 3**) | **VA** | **VB** | **VC** | **VD** |
| ESCON **AnIn2−** (**J6 pin 4**) | DAC GND | DAC GND | DAC GND | DAC GND |
| ESCON **GND (Digital I/O)** (**J5 pin 5**) | module's distributor board | ← | ← | ← |
| ESCON **GND (Analog I/O)** (**J6 pin 7**) | module's distributor board | ← | ← | ← |
| IAA100 **Vout** → Teensy (force) | pin **14** (A0) | pin **15** (A1) | pin **16** (A2) | pin **17** (A3) |
| IAA100 **GND** | module's distributor board | ← | ← | ← |
| Distributor board → Teensy **G** | one wire per module (white on the traced driver) | ← | ← | ← |
| 24 V PSU **+V / −V** (Mean Well RS-15-24, 15 W; **4 units, one per amplifier**) | IAA100 power terminal **pin 1 (+Vin) / pin 2 (GND)** | ← | ← | ← |
| 48 V PSU **+V / −V** (Mean Well RSP-2000-48, no power switch) | shunt regulator (maxon 235811) pins **4 / 5** (input); its pins **6 / 7** (output 1) → ESCON **J1** + / − | ← | ← | ← |
| DYMH-103 load cell | IAA100 input | ← | ← | ← |
| Maxon motor + Hall sensors | ESCON J2 motor (1–3 windings, 4 shield) / J3 Hall (1–3 Hall 1–3, **4 +5 V, 5 GND**) | ← | ← | ← |
| ⚠️ Module C found 2026-10-01 | J3 pin 5 (GND) empty → Hall error | | | |

Per module, the Teensy side uses 3 signal wires (enable, setpoint, force) plus grounds.
Grounds: each module has its **own distributor board** in the frame (found 2026-09-30) joining ESCON J5.5, J6.7 and the IAA100 GND;
one wire per module runs from it to Teensy GND. This is the manual's "Distributor".

## Found on the lab cabling (2026-09-30): module C (right)
Tape removed from the J5/J6 cable. Colours below are **at the ESCON end**; the jumper-end colours differ (spliced).

| Set | Jumper end | Wire (ESCON end) | Connected to | Meaning | Plug into (breadboard) |
|---|---|---|---|---|---|
| 3 wires | **black** | yellow | ESCON J5 pin 2 | DigIN2, **enable** | Teensy **29** |
| 3 wires | yellow | pink | nothing | spare | leave unconnected |
| 3 wires | white | black | nothing | spare | leave unconnected |
| 4 wires | **red (female)** | blue | ESCON J6 pin 3 | AnIN2+, **setpoint +** | DAC **VC** (onto the pin) |
| 4 wires | **orange** | green | ESCON J6 pin 4 | AnIN2−, **setpoint −** | DAC GND |
| 4 wires | **blue** | brown | Futek IAA100 "Out" | **force** | Teensy **16** (A2) |
| 4 wires | **purple** | white | module's **distributor board** (ESCON J5.5 + J6.7 + IAA100 GND) | **ground** | Teensy G |

Jumper colours are counter-intuitive (black = enable, purple = ground): **label the jumper ends** before reconnecting.

Matches the per-module table above: all 7 wires accounted for. J6.3 blue / J6.4 green confirmed (the "J5 3/4" report was a typo). Check the Futek terminal of the yellow ground wire is labelled GND.
Module: "right side motor" = C (pulls the subject to the right, `hardware.md`); confirm the viewpoint (subject's right, facing the walking direction).
Still to record: the same trace for modules A, B (and D); colours may differ.

## Not in the sources (look up before wiring)
- ~~ESCON pin numbers~~: model is **ESCON 70/10** (422969); J5/J6 pins above are from its hardware reference (`escon/`). Never connect J5 pin 6 (+5 V) or J6 pins 5–6 (AnOUT, −4…+4 V) to the Teensy.
- Which **wire colour** of the existing jumper cables sits in which J5/J6 position (2 sets per driver: 3 wires + 4 wires, `docs/hardware-photos/`). On the traced driver: 3 go to the ESCON (J5.2, J6.3, J6.4), 1 to the IAA100 Out, 1 to the frame board, 2 are spares (section above). Jumper-end colours still to map.
- IAA100 terminals (Futek IAA100/IAA200 quick start guide + product manual, media.futek.com): power side 5-way: **1 +Vin (12.5–26 V DC), 2 GND (power), 3 shunt cal (empty), 4 GND (output), 5 Vout**; sensor side 4-way: 1 +excitation, 2 +signal, 3 −signal, 4 −excitation/shield. Matches thesis Fig. 7 (signal on 5, ground on 4). Wire the 24 V with the supply unplugged. Still open: load cell ↔ IAA100 colours (DYMH-103 datasheet).
- Shunt regulator ↔ ESCON power terminals; motor and Hall cables (Maxon standard cables).
- Which load cell / sensor number belongs to which module (`calibration.md`: assumed S1 = A … S4 = D).

## Power order
- Reading ESCON settings: USB into ESCON J7 first → 48 V on (24 V not needed; enable wire unplugged). 48 V off before unplugging USB.
- Motor test, up: Teensy USB (boots DISARMED) → 24 V (amplifier) → check force reading → 48 V → `bumpem arm`.
- Down: `bumpem release` / `estop` → 48 V off → 24 V off → USB.
- 24 V before 48 V: without the amplifier the Teensy reads 0 N and the closed loop keeps raising the current.

## Power supplies and e-stop (Stanford guide pp. 14–16)
- RSP-2000-48 **−V → shunt pin 5**, **+V → shunt pin 4**, **⏚ → shunt pin 3**; shunt **pins 6/7 → ESCON J1 +/−** (guide p. 16 table, regulator label).
- Shunt regulator DIP: Stanford **55 V = switches 3 and 5 ON** (Vth = 75 V − (4 + 16) × 1 V). IBMS setting unknown.
- Mains side (⏚ L N, 230 V) of both supplies: lab technician only.
- **E-stop** (guide pp. 13–15, Mean Well RSP-2000 datasheet p. 4 + p. 6 in `docs/reference/`):
  - Button with an **SPST-NO** contact block (normally open; Stanford swapped the stock red NC block for a green NO block).
  - Two 24 AWG wires from the contact to the supply's **CN501 pin 7 (Remote ON-OFF)** and **pin 11 (+5V-AUX)**; either wire on either pin.
  - Datasheet: *short* between pin 7 and pin 11 = **power OFF**; *open* = **power ON**. Pressing the button closes the contact → 48 V output off.
  - **Not fail-safe:** a cut wire = open = power stays ON (guide p. 15 warning). **Test before every session.** A fail-safe variant needs extra hardware (e.g. an NC contact driving a relay): ask the technician.
  - CN501 is a Hirose **DF11-12DP** header. Stanford soldered to it; the reversible option is a mating housing **DF11-12DS** with **DF11 crimp terminals** (datasheet p. 6).
  - One RSP-2000 per module means one contact per supply: stack one NO contact block per supply on the same button (keep each pair separate; the control is isolated per unit).
  - The e-stop only switches the 48 V output. Mains and the supply's +5 V/+12 V aux outputs stay live.
- Pressing it removes all rope tension (intended). The GRAIL treadmill e-stop stays the primary stop (`safety.md`).

## Checks (from the 2026-09-29 desk test)
- Remove any loopback jumpers (DAC VA–VD → pins 14–17) before connecting amplifiers.
- Before 24 V / 48 V: continuity per wire, and no continuity between 3V and GND.
- After wiring, with 48 V off: `bumpem arm` → DAC VA–VC ≈ 0.51 V open-loop (kp = kd = 0), enable pins 27–29 high.

## Thesis design check (2026-10-01)
Thesis §2.4/§2.7/§2.8 per module: ESCON motor driver, brake chopper (= maxon shunt regulator), 48 V supply (one per module), load cell + Futek IAA100, **24 V supply for the IAA100 only** (§2.7), distributor (common ground). Shared: Teensy 4.1 + MCP4728. Encoder: not used (§7 lists it as future work). E-stop: thesis mentions only the treadmill's.
The thesis does not describe the Hall sensor wiring. maxon/ESCON documents put Hall GND on ESCON J3 pin 5, which is empty on two modules (2026-10-01).

## Motor connector → ESCON (maxon EC 90 flat 500267 = V1, catalog p. 327, `docs/reference/maxon-500267-catalog-page.pdf`)
One 8-pin Molex 46015-0806 on the motor:
| Motor pin | Signal | ESCON |
|---|---|---|
| 1 | Hall sensor 1 | J3 pin 1 |
| 2 | Hall sensor 2 | J3 pin 2 |
| 3 | VHall 4.5–24 VDC | J3 pin 4 (+5 V) |
| 4 | Motor winding 3 | J2 pin 3 |
| 5 | Hall sensor 3 | J3 pin 3 |
| 6 | GND (Hall) | J3 pin 5 |
| 7 | Motor winding 1 | J2 pin 1 |
| 8 | Motor winding 2 | J2 pin 2 |
J2 pin 4 = cable shield (no signal).

**Module C found (2026-10-01):** J2 = red, brown, white + **blue on pin 4 (shield)**; J3 = yellow, pink, grey, green, **pin 5 empty**. 8 wires for 8 motor pins → the **blue wire is most likely the Hall GND (or VHall) on the wrong terminal**. Same on a second module. Confirm at the motor connector (colour per pin), then move blue J2.4 → J3.5 if it is motor pin 6.

**Module C motor connector, read from the wire side (2026-10-01):** top row L→R brown, red, blue, grey; bottom row L→R white, green, pink, yellow.
Mirrored numbering (wire side): yellow 1 Hall 1, pink 2 Hall 2, green 3 VHall, white 4 winding 3, grey 5 Hall 3, **blue 6 GND**, red 7 winding 1, brown 8 winding 2.
Matches the ESCON wiring for 7 of 8 wires (J2: red/brown/white = windings 1/2/3; J3: yellow/pink/grey/green = Hall 1/2/3/+5 V). **Blue = Hall GND, sits on J2 pin 4 (shield) → move to J3 pin 5.** Assumes colours continuous motor → ESCON (consistent with all other wires).
**Fixed 2026-10-01:** module C blue (Hall GND) moved J2 pin 4 → **J3 pin 5** → ESCON LED **green**, Hall error gone. J2 pin 4 now empty (shield, unused). Apply the same check/fix to every module.

## Breadboard wire colours (convention from 2026-10-02)
For wires placed on the breadboard: **black = GND** (incl. Teensy G → blue − rail, pin 16 → rail), **red = 3.3 V**, **yellow = SCL**, **blue = SDA**, other colours = module signals. Red + rail stays empty.
Do not copy thesis Fig. 7 (it uses red for ground). The ESCON harness jumpers keep their own colours and do **not** follow this (black = enable, purple = GND, red = SP+, orange = SP−, blue = force): label their ends.
Actual breadboard (2026-10-02): **− rail** = T G, D GND, T 16 (short wire), module C purple (GND), orange (SP−); **+ rail** = T 3V, D VCC (3.3 V only, labelled); direct: T 19 → D SCL (**purple**), T 18 → D SDA (**white**), T 29 ← black (enable), D VC ← red (SP+). ⚠️ Two purple wires near the Teensy (SCL and module C GND): label them.

## Recabling plan (2026-10-02): one colour from ESCON to breadboard
The jumper extensions are replaced so each wire keeps its ESCON-side colour. Per module: **yellow = enable** (J5.2 → T 27 / T 29), **blue = setpoint +** (J6.3 → D VA / D VC, needs a **female end**), **green = setpoint −** (J6.4 → − rail), **white = ground** (distributor → − rail), **brown = force** (IAA100 Out → T 14 / T 16 later; not plugged now), pink + black = spares (taped).
⚠️ SDA (T 18 → D SDA) is also white: label it or change it to grey. Drawing: `docs/diagrams/cabling-4-modules.png`.

**Module A J3 (2026-10-02): green and grey were swapped** (Hall supply ↔ Hall 3) → strong uncontrolled pull. Correct for every module: J3 1 yellow, 2 pink, 3 grey, 4 green, 5 blue; J2 1 red, 2 brown, 3 white, 4 empty. Check J2/J3 on every module against this before first drive.

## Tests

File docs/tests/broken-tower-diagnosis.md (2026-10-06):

# Broken tower: unpowered diagnosis

The tower listed as out of service in the thesis (48 V supply and brake chopper suspected shorted, before 2026-10).
Everything unplugged from mains, Teensy and other modules. Meter: **Ω** = resistance mode, **▶|** = diode mode.
**OL** (or `0L`, `1`) = open, no connection. Always write the unit shown (Ω, kΩ, MΩ, V).
"Rising" = the value keeps climbing (capacitors charging): write where it is after ~10 s.

## 0. Meter
| # | Mode | Red | Black | Expected | Result |
|---|---|---|---|---|---|
| 0a | Ω | probes touching | | ~0 Ω | 0 |
| 0b | Ω | probes in the air | | OL | OL |
| 0c | ▶| | probes touching | | ~0 | 0 |
| 0d | ▶| | probes in the air | | OL | OL |

## 1. Brake chopper (shunt regulator, maxon 235811), all wires off its terminal block
| # | Mode | Red | Black | Expected (healthy) | Result |
|---|---|---|---|---|---|
| 1a | Ω | pin 4 (+V in) | pin 5 (−V in) | rising, not ~0 | rising, 30 kΩ at 20 s |
| 1b | Ω | pin 5 | pin 4 | a value, not ~0 | falling, MΩ range |
| 1c | Ω | pin 6 (out) | pin 7 (out) | rising or a value, not ~0 | rising, kΩ |
| 1d | Ω | pin 4 | pin 3 (⏚) | OL | OL |
| 1e | Ω | pin 5 | pin 3 (⏚) | OL | OL |
| 1f | Ω | pin 4 | metal housing / heat sink | OL | OL |
| 1g | ▶| | pin 5 | pin 4 | ~0.3–0.7 V (protection diode) | 0.487 V |
| 1h | ▶| | pin 4 | pin 5 | OL or slowly rising | slowly rising |

## 2. Motor driver (ESCON 70/10), every connector unplugged (J1, J2, J3, J5, J6, USB)
| # | Mode | Red | Black | Expected (healthy) | Result |
|---|---|---|---|---|---|
| 2a1 | Ω | J1 + | J1 − | rising, not ~0 | rising |
| 2a2 | Ω | J1 − | J1 + | a value or rising, not ~0 | 20 kΩ |
| 2b1 | ▶| | J2 pin 1 | J1 + | ~0.3–0.7 V | 0.496 V |
| 2b2 | ▶| | J1 + | J2 pin 1 | OL | OL |
| 2b3 | ▶| | J1 − | J2 pin 1 | ~0.3–0.7 V | pass |
| 2b4 | ▶| | J2 pin 1 | J1 − | OL | pass |
| 2b5 | ▶| | J2 pin 2 | J1 + | ~0.3–0.7 V | pass |
| 2b6 | ▶| | J1 + | J2 pin 2 | OL | pass |
| 2b7 | ▶| | J1 − | J2 pin 2 | ~0.3–0.7 V | pass |
| 2b8 | ▶| | J2 pin 2 | J1 − | OL | pass |
| 2b9 | ▶| | J2 pin 3 | J1 + | ~0.3–0.7 V | pass |
| 2b10 | ▶| | J1 + | J2 pin 3 | OL | pass |
| 2b11 | ▶| | J1 − | J2 pin 3 | ~0.3–0.7 V | pass |
| 2b12 | ▶| | J2 pin 3 | J1 − | OL | pass |
Faulty: ~0 in both directions on any pair = shorted power stage.

## 3. Motor (maxon EC 90 flat 500267), on its own cable, ESCON unplugged
| # | Mode | Red | Black | Expected (healthy) | Result |
|---|---|---|---|---|---|
| 3a | Ω | red winding wire | brown | ~0.8–1 Ω (datasheet 0.844 Ω + cable) | 1 Ω (0a = 0, measured at the J2 plug incl. cable) |
| 3b | Ω | brown | white | ~0.8–1 Ω | 0.9 Ω |
| 3c | Ω | white | red | ~0.8–1 Ω | 0.9 Ω |
| 3d | Ω | red winding wire | motor metal body | OL | |
Subtract reading 0a from 3a–3c.

## 4. Old 48 V supply (Mean Well RSP-2000-48), **mains plug out**, output wires off
| # | Mode | Red | Black | Expected (healthy) | Result |
|---|---|---|---|---|---|
| 4a | Ω | +V out | −V out | rising, not ~0 | passed |
| 4b | Ω | +V out | ⏚ | OL | passed |
| 4c | Ω | −V out | ⏚ | OL (or very high) | passed |
| 4d | look | burn marks, bulged parts, smell, blown fuse visible through the vents | | none | **white residue coming out of the case** (likely capacitor electrolyte) |
Do not open the supply and do not touch its mains terminals.

## 5. Brake chopper powered from a 24 V supply (Mean Well RS-15-24, current-limited by its short-circuit protection)
Source: `docs/reference/maxon-235811-dsr-70-30-operating-instructions.pdf` (supply 12–70 V, no-load 15 mA, 8800 µF inside,
threshold Vth = 75 V − (sum of DIP switches ON: S1=1, S2=2, S3=4, S4=8, S5=16, S6=32) × 1 V, yellow LED = shunt active, red LED = over-temperature).
Wiring: 24 V + → pin 4, 24 V − → pin 5, nothing else. Pins 6/7 (output 1) are in parallel with the input.
| # | Check | Expected (healthy) | Result |
|---|---|---|---|
| 5a | DIP switches S1–S6 (before power): write ON/OFF, compute Vth | Vth above 48 V (e.g. 53 V) | **all OFF → Vth = 75 V** (photo IMG_9788). The 3 working towers: S3 + S5 ON → **55 V** (IMG_9784/9785/9787). ON = lever toward the "ON" print (right), away from the numbers |
| 5b | Pins 4–5 (DC V) after switch-on | ~24 V (may take ~1 s: the supply charges 8800 µF) | 24 V |
| 5c | Pins 6–7 (DC V) | same as 5b | 24 V |
| 5d | Yellow LED (shunt active) / red LED (over-temperature) | both off | both off |
| 5e | Housing after 5 min, sound, smell | cool, silent, no smell | passed |
| 5f | After switch-off: pins 4–5 before touching the wires | wait until < 1 V (the capacitors hold charge) | |
Faulty: 5b well below 24 V or the supply clicking on/off (short), or yellow LED on with Vth > 24 V.

**DIP finding (2026-10-06).** Vth 75 V is above the ESCON 70/10 supply maximum (70 V) and above the RSP-2000-48 over-voltage protection (57.6–67.2 V, `docs/reference/meanwell-rsp-2000-spec.pdf`; it shuts the output down, "re-power on to recover").
With 75 V the chopper never clamps braking energy below those limits; with 55 V (working towers) it does. Plausible cause of the failure (bus pumped up when the motor brakes), not proven: the DIP could also have been changed after the failure. Neither the Stanford guide nor the thesis/manual states a threshold.
**Set to 55 V (S3 and S5 ON) on 2026-10-06**, like the other towers. Then 5b–5f at 24 V.

## Result
| Part | Verdict | Date |
|---|---|---|
| Brake chopper | passes all meter tests, 24 V and 48 V powered tests (new 48 V supply, no fuse, ~5 min: 48 V on pins 6–7, LEDs off, no heat). DIP set to 55 V like the other towers | 2026-10-06 |
| ESCON 70/10 | passes all meter tests (power input, all 6 transistor diodes; meter battery died mid-series, 2b7–2b12 repeated with a new one). Powered at 48 V via the chopper: J1 only → red 5× (Hall error, expected); with motor J2 + J3 → green slow blink (DISABLE), motor still. Settings in ESCON Studio not yet compared with module A | 2026-10-06 |
| Motor | windings 1 / 0.9 / 0.9 Ω; Hall sensors OK (ESCON reports no Hall error with J3 connected); 3d (winding to body) not yet measured | 2026-10-06 |
| Old 48 V supply | **faulty**: 4a–4c passed but white residue leaking from the case → scrap (e-waste), replace | 2026-10-05 |

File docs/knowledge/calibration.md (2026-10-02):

# Load cell calibration

Source: thesis §3.2, Table 1.

Method: known masses 6/8/12 kg (58.86/78.48/117.72 N). IAA100 zero/span trimmed so 0–3.3 V ↔ 0–200 N.
Firmware uses one linear map for all modules: `f = raw/1023*200` (`.ino:233`). No per-sensor coefficients in code.

| Target (N) | S1 | S2 | S3 | S4 |
|---|---|---|---|---|
| 0 | 0.39 | 0.29 | 0.37 | 0.10 |
| 58.86 | 57.67 | 56.36 | 56.11 | 57.36 |
| 78.48 | 77.03 | 78.59 | 76.25 | 77.31 |
| 117.72 | 117.50 | 119.65 | 117.30 | 118.47 |

Mean error ≈ 1.7 %, max < 2.5 %.

Unknown: sensor N ↔ module letter mapping. Assumed S1=A … S4=D. Verify.
Resolution: 200 N / 1023 ≈ 0.2 N per ADC count.

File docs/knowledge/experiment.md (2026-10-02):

# Experiment protocol (thesis pilot)

Source: thesis §4.1–4.3; manual §6.1; `legacy/MATLAB_script.m:10-17`.

- Speed 3.3 m/s; warm-up 5 min at 2.7 m/s; 3 min rest between trials.
- Per trial: 25 perturbations = 5 blocks × shuffled `["a","b","c","ab","bc"]`.
- Each perturbation at a random valid FS count in [50, 75] since the last one.
- 100 N target, baseline 5 N.
- 2 trials per participant.

## Procedure order (manual §6.1)
Power on → ESCON check → flash Teensy (auto-ramps to baseline) → verify baseline on all modules → treadmill (D-Flow) to speed → start detection script → monitor → script ends after last perturbation → treadmill stop → then stop control.

## Outputs (MATLAB)
- `Logs/Log_event_data_<ts>.csv`: `time_s,frame,subIndex,Fz_total,event`
- `Logs/Perturbation_log_<ts>.csv`: `perturbation_index,fs_number,time_s,frame,subIndex,command`
- Teensy force telemetry is **not** captured by the MATLAB script.

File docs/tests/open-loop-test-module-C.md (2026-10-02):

# Preliminary open-loop test: Teensy drives module C (no force sensor)

Goal: check that the Mac → USB → Teensy → DAC → ESCON → motor chain works, before the amplifier is connected.
The Teensy runs **open-loop** (PD gains 0): target force → feedforward current → DAC → ESCON. The force reading is ignored.
Nothing measures the real force, so forces stay small.

## Why these settings
Confirmed values: ESCON set value **10 V = 30 A** (`escon/moduleA_left_2026-10-01.edc`), motor torque constant **0.231 Nm/A** (maxon 500267), drum radius 0.01905 m.
Firmware feedforward: `ides = kff · F · rc / kt` with firmware `kt = 0.1524`, DAC full scale = `i_full` = 30 at 3.3 V.
Real force / target = kff · (3.3 V / 30) · (3 A/V) · (0.231 / 0.1524) ≈ **0.5 · kff**. Default `kff = 7.5` → about **3.75× the target**; **`kff = 2` → about 1× the target**. Calculated, not measured; friction makes the real pull lower.

| Setting | Value | Reason |
|---|---|---|
| `kp_track` `kd_track` `kp_pulse` `kd_pulse` | 0 | open-loop |
| `kff` | 2 | target ≈ real pull |
| `baseline_n` | 2 | gentle hold |
| `fmax_n` | 30 | firmware refuses targets above 30 N |
| `ch_A` `ch_B` | 0 | only C (D is off by default) |

Settings live in Teensy RAM: unplugging the Teensy's USB restores the closed-loop defaults.

## Wiring (Teensy USB out, 48 V off; right-side blue − rail as ground)
Actual layout (2026-10-02, T = Teensy, D = DAC): **− rail** T G, D GND · **+ rail** T 3V, D VCC (3.3 V only) · T 19 → D SCL (purple wire) · T 18 → D SDA (white wire). ⚠️ SDA wire and module C ground are both white: label them (or make SDA grey). Colours per `knowledge/wiring.md` → Recabling plan. Check + rail ↔ − rail does NOT beep. Loopback wires to 14–17 removed (2026-10-02).

| # | From | To |
|---|---|---|
| 1 | T G (right-edge top G row, free hole) | blue − rail (right side) |
| 2 | white (module C ground, after recabling) | blue − rail |
| 3 | green (SP−) | blue − rail |
| 4 | short wire from T 16 row | blue − rail (force input reads 0) |
| 5 | yellow (enable) | T 29 row (left edge, a/b) |
| 6 | blue (SP+, female end) | D VC pin |
| — | red + rail | nothing |
| — | brown (force), pink, black (spares) | not plugged, ends taped |

Checks: rail continuity between all four rail holes (rails can be split mid-board) · T 3V ↔ − rail must NOT beep · nothing in the 5V row, the + rail, or rows 14, 15, 17.
ESCON: J1 power, J2 motor, J3 Hall (blue on pin 5) as fixed on 2026-10-01.

Script: `scripts/open_loop_test.sh` (C), `… A` (A) or `… AC` (both, same pulse at the same time) runs Setup, Dry run and Run below with prompts for the 48 V. Pulse duration 400 ms (shortened from 600 on 2026-10-02). AC only after A and C each passed alone; switch the two 48 V supplies on one at a time, separate sockets.

## Setup
Rope tied to a fixed anchor · no person · treadmill off · everyone clear · **hand on the 48 V strip switch** (e-stop not wired yet).

```sh
conda activate BumpemHome
P=/dev/cu.usbmodem169222501
bumpem info --port $P                      # expect proto=1, fw=1.0.0
for k in kp_track kd_track kp_pulse kd_pulse; do bumpem set $k 0 --port $P; done
bumpem set kff 2 --port $P
bumpem set baseline_n 2 --port $P
bumpem set fmax_n 30 --port $P
bumpem set ch_A 0 --port $P
bumpem set ch_B 0 --port $P
bumpem get --port $P                       # check the values above
```

## Dry run (48 V off)
`bumpem arm --port $P --watch 3` → C target 2.0 · `bumpem pulse C=20 --rise 50 --dur 400 --fall 50 --port $P --watch 2` → 2 → 22 → 2 · `bumpem release --port $P`.

## Run
| # | Action | Expect | Stop if |
|---|---|---|---|
| 1 | 48 V strip **on** | ESCON LED green **blinking** (disabled) | red LED |
| 2 | `bumpem arm --port $P --watch 3` | LED **steady green** (enabled); rope tightens gently over 2 s | hard pull, motor spins |
| 3 | `bumpem pulse C=5 --rise 50 --dur 400 --fall 50 --port $P --watch 2` | small tug; telemetry: C target 2 → 7 N, DAC C rises | drum pays out instead of pulling |
| 4 | same with `C=10` | bigger tug | |
| 5 | same with `C=20` | clear tug (~22 N target) | |
| 6 | `bumpem release --port $P` | rope slackens over 1 s; LED back to blinking | |
| 7 | 48 V strip **off** | | |

Emergency: strip switch off, or `bumpem estop --port $P` from a second terminal.

## Report
For each step: what the LED did and what the rope did (gentle / tug / nothing / wrong direction). The CLI telemetry shows target and measured only (measured C ≈ 0 because pin 16 is grounded).
Expected DAC codes (not shown by the CLI): baseline 68, C=5 → 238, C=10 → 409, C=20 → 750 (≈ 0.05–0.6 V on VC).

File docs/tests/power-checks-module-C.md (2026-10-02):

# Electrical checks before first power-on: Bump'em module C

Self-contained test specification. It can be read without any other document.

## Context
- System: Bump'em cable-perturbation device. Module C ("right" module) consists of:
  - PSU = Mean Well RSP-2000-48 switching power supply. Output 48 V DC, up to 42 A. Screw terminals labelled −V, +V, ⏚ (protective earth), L, N (230 V mains). Small 12-pin control connector CN501 (Hirose DF11-12DP). No power switch: it is on whenever its mains plug is live.
  - SHUNT = maxon Shunt Regulator 235811 (DSR 70/30). Green 10-way screw terminal block. Pins: 1–2 external resistor (unused), 3 ground safety earth, 4 +Vcc input, 5 Power Gnd input, 6 +Vcc output 1, 7 Power Gnd output 1, 8 ground safety earth, 9–10 output 2 (unused). Internal 6-way DIP switch sets its dump threshold: Vth = 75 V − (sum of ON switches, where switch n = 2^(n−1) V).
  - ESCON = maxon ESCON 70/10 motor driver. Power connector J1 (+ / −). USB socket J7.
  - E-STOP = emergency-stop button with one contact block (2 wires).
- Intended wiring:
  - PSU −V → SHUNT pin 5
  - PSU +V → SHUNT pin 4
  - PSU ⏚ → SHUNT pin 3 (PSU ⏚ also carries the mains earth wire)
  - SHUNT pin 6 → ESCON J1 +
  - SHUNT pin 7 → ESCON J1 −
  - E-STOP contact → PSU CN501 pin 7 (Remote ON-OFF) and pin 11 (+5V-AUX). Datasheet: short between pin 7 and 11 = PSU output OFF; open = ON. Required contact type: normally open (NO).
- Current state: all wiring done, PSU mains plug NOT connected. Motor-enable wire from the controller is disconnected, so the motor cannot move.

## Safety rules (apply to every test)
1. Continuity tests (T0–T4) only with the PSU mains plug disconnected.
2. Voltage tests (T6–T7) with power on: touch only with probe tips, never with fingers; never touch L / N.
3. Meter probes: black in COM, red in VΩ. Never use the A / mA / 10A sockets.
4. Meter modes: continuity = ))) symbol (beep); DC voltage = V⎓ (V with straight + dashed line), range ≥ 200 V for 48 V and ≥ 20 V for 5 V / 3.3 V.
5. Any FAIL → stop, do not power on, report the reading.

## T0: residual voltage (meter: DC volts)
- Measure PSU +V to PSU −V.
- PASS: about 0 V. FAIL: > 1 V → wait for capacitors to discharge and repeat.

## T1: meter self-test (meter: continuity)
- Touch probes together. PASS: beep, about 0 Ω.

## T2: short between + and − (meter: continuity)
- PSU +V to PSU −V.
- PASS: no beep, OR a short chirp that stops / a resistance that rises or settles in the kΩ range (capacitors charging).
- FAIL: steady beep, about 0 Ω → short circuit. Do not power on.

## T3: wiring and polarity (meter: continuity)
| # | Probe 1 | Probe 2 | PASS |
|---|---|---|---|
| T3.1 | PSU +V | SHUNT pin 4 | beep |
| T3.2 | PSU +V | SHUNT pin 5 | NO beep (beep = polarity swapped) |
| T3.3 | PSU −V | SHUNT pin 5 | beep |
| T3.4 | PSU ⏚ | SHUNT pin 3 | beep |
| T3.5 | SHUNT pin 6 | ESCON J1 + | beep |
| T3.6 | SHUNT pin 7 | ESCON J1 − | beep |

## T4: earth isolation (meter: continuity)
| # | Probe 1 | Probe 2 | PASS |
|---|---|---|---|
| T4.1 | PSU +V | PSU ⏚ | no steady beep |
| T4.2 | PSU −V | PSU ⏚ | record result only (PSU output is isolated from earth per datasheet; unknown whether SHUNT ties Power Gnd to safety earth internally) |

## T5: e-stop contact type (meter: continuity, across the two e-stop wires, e-stop disconnected from CN501 or PSU unplugged)
- Button released: PASS = no beep. Button pressed: PASS = beep. → contact is NO (correct).
- Reversed behaviour = NC contact → FAIL: replace the contact block with an NO type.

## T6: shunt threshold (visual)
- Read the SHUNT's internal DIP switch (not the example drawings on its label). Compute Vth = 75 − Σ 2^(n−1) over ON switches n.
- PASS: Vth clearly above 48 V and below 70 V (reference build: switches 3 and 5 ON → 55 V).
- FAIL: Vth ≤ 50 V → the shunt would dissipate continuously and overheat.

## T7: first power-on (only if T2, T3, T5, T6 pass)
Setup: PSU plugged into a switched power strip, strip switch OFF. Socket not shared with other experiments. Location of the room's breaker panel known. Optional: ESCON USB (J7) connected to a PC before power-on (never plug USB into a powered ESCON).
1. Switch strip ON. Observe 30 s without touching:
   - PASS: SHUNT LED "Power Dissipation Active" stays OFF; SHUNT LED "Overtemperature" OFF; ESCON status LED lights; PSU fan may run.
   - FAIL: dissipation LED ON, smoke, smell, buzzing, breaker trips → switch OFF.
2. Meter DC volts, SHUNT pin 4 (red) to pin 5 (black): PASS = 47–49 V (PSU adjustable 42–56 V).
3. E-stop (if wired): press → ESCON LED goes off (PSU output off); release → back on. PASS = both.
4. Optional, PSU on: CN501 pin 11 to pins 8–10 = about +5 V (identifies pin 11).
5. Switch strip OFF. Wait 1 min before touching wiring.

## Report format
T0 … T7 each: PASS / FAIL + reading (e.g. "T2 PASS, chirp then open"; "T4.2: beep 0.3 Ω"; "T6: switches 3,5 ON → 55 V").

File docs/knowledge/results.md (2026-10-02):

# Reference performance (regression targets)

Source: thesis Tables 2–5. Use these to check that a refactor did not degrade behavior.

Rise time = time to 80 % of target. Peak = max in impulse window.

| Dir | Module | 100 N peak | 100 N rise (ms) | 150 N peak | 150 N rise (ms) |
|---|---|---|---|---|---|
| left | 1 (A) | 91.6 ± 0.6 | 30.0 ± 3.6 | 135.5 ± 5.5 | 32.5 ± 5.0 |
| front | 2 (B) | 100.6 ± 4.5 | 34.0 ± 5.5 | 140.6 ± 0.9 | 30.0 ± 0.7 |
| right | 3 (C) | 114.9 ± 5.5 | 34.0 ± 8.9 | 127.4 ± 2.7 | 45.0 ± 5.8 |
| front-left | 1+2 | 81.7 ± 4.1 | 40.0 ± 8.2 | 123.5 ± 2.6 | 40.0 ± 10.0 |
| front-right | 2+3 | 94.8 ± 6.5 | 42.0 ± 4.5 | 131.6 ± 2.6 | 37.5 ± 5.0 |

Overall at 100 N: peak 96.7 ± 12.3 N, rise 36.0 ± 4.9 ms.
Baseline tracking: 5 N and 10 N stable, no drift (§5.1).

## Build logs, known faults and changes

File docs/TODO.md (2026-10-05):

# To do

Ordered by **danger** first, then by **what it blocks**. Work top to bottom; items in the same step can run in parallel.
Tick items off and tell Claude what you found so `STATUS.md` stays current. Rewritten 2026-10-02 (evening), updated 2026-10-05.

**Danger:** 🔴 high = injury or burnt hardware if skipped/done wrong · 🟠 medium = damaged electronics or misleading test · 🟢 low.
**Blocks:** the steps that cannot start until this one is done.

Teensy port on the Mac: `/dev/cu.usbmodem169222501` (written `PORT` below). Every new Terminal: `conda activate BumpemHome`.
**State (2026-10-02):** modules **A (left), C (right), D (back)** mounted and pulled correctly in the open-loop test (no force sensing); B (front) not installed.
Server 0.2.0: board API + perturbation by angle (`bumpem perturb`), simulator-tested only. E-stop **not wired**: the 48 V strip switch is the only stop. Carrier board designed, not ordered.

---

## ▶ Next session
- [ ] 🟢 Fix `scripts/open_loop_test.sh`: keep `AC`, usage text = real modes, `ACD` power-on prompt must name all three supplies (A, C, **D**), "with AC both at once" text. Then commit (`scripts: ...`)
- [ ] 🟠 Try `bumpem perturb` on the hardware, open-loop settings of the script, rope to fixed anchors, nobody attached:
  `bumpem set ch_D 1` (the firmware boots with D off) → `arm` → `perturb 180 10`, `perturb 135 10`, `perturb -90 10`, `perturb 90 10` (`--dur 400 --phase2 50 --watch 2`). Expect D / A+D (7.07 N each) / C / A
- [ ] 🟢 Same through the server: `bumpem serve --board PORT` → http://127.0.0.1:8000/docs → `POST /perturbation`
- [ ] 🟢 `git push` in BumpemServer (9 commits ahead of GitHub); delete the empty clone `IBMS_Offenburg/BumpemServerGit`

## 1. 🔴 Safety · blocks long sessions and anything with a person attached
- [ ] **Multimeter**: borrow one (lab / makerspace) or buy one. Needed for the e-stop test, the 24 V checks and the amplifier range check
Details: `knowledge/wiring.md` → Power supplies and e-stop; `docs/power-estop-checklist.md`.
- [ ] Order a **Hirose DF11-12DS** housing + **DF11 crimp terminals** for each RSP-2000's CN501 (or plan to solder)
- [ ] **Wire the e-stop**: CN501 pin 7 + pin 11, one NO contact per 48 V supply (A, C, D)
- [ ] Ask the technician whether a **fail-safe** e-stop is possible (in this design a cut wire means the button does nothing)
- [ ] **Test:** 48 V on, press → every ESCON LED off; release → back on. **Repeat before every session**
- [ ] Ask your **supervisor**: electrical safety inspection (DGUV Vorschrift 3)? Who fixes mains cables?
- [ ] Mains, look only: confirm **one RSP-2000-48 per module**; each on its own socket/circuit; RS-15-24 (24 V) units: plug, L / N / ⏚ tight, earth, cover, strain relief. Anything wrong → stop, university fixes it
- [ ] Shunt regulator: photo of the DIP switch block (threshold must stay clearly > 48 V; Stanford 55 V). Tell Claude before changing anything

## 2. 🟠 Force sensing → closed loop · blocks real force control, logging, trials with people
**Decision 2026-10-05:** zero / sensitivity / calibration checks and the closed-loop test wait for the **carrier board** (breadboard contacts made the readings unreliable: C 73 N, then A/D shifting after replugging). Until then only open-loop tests (force not used; over-force cut-out at `fault_n` 195 N).
- [ ] 🔴 **Now:** repair C's **cut white ground wire** (found 2026-10-05); inspect A's and D's cables for damage
- [ ] After the carrier board: `scripts/force_check.py` (all zeros a few N) → weight calibration 6 / 8 / 12 kg per module (incl. the 200 kg cell) → closed-loop test
Power order: Teensy USB → **24 V** → check force → **48 V** → arm. Down: release → 48 V off → 24 V off.
- [x] RS-15-24 **+V → IAA100 pin 1 (+Vin), −V → pin 2 (GND)** on A, C, D (2026-10-05), supply unplugged while wiring (`knowledge/wiring.md`). Check first: the existing brown wire is on pin 5 and the ground on pin 4; if not, photo to Claude. Don't touch DIP switches / zero / span. 24 V output: no short before connecting
- [ ] **C rests at ~73 N** (`scripts/force_check.py`, 2026-10-05; A 4.6 N, D 1.3 N): swap C/D brown wires (does it follow?), then jumper C's IAA100 pin 4 → − rail (ground?). Don't pull C hard meanwhile (3.3 V reached at ~127 N real force)
- [ ] **Amplifier range** per module (needs the multimeter): brown wire out of the Teensy, pull hard → output **≤ 3.3 V** (`knowledge/calibration.md`: 0–3.3 V = 0–200 N). Hand pulls so far stayed ≤ ~2.4 V at the Teensy, but above 3.3 V the Teensy can't tell (reads 200 N) and can be damaged
- [x] Short wires removed, brown force wires in T14 (A), T16 (C), T17 (D) (2026-10-05)
- [x] Hand-pull check `scripts/force_check.py` (2026-10-05): left → A, right → C, back → D, each moves only its own sensor. Zeros: A 4.6 N, C **73 N** (item above), D 1.3 N
- [ ] Claude: CSV logging for `--watch` / server (to compare with `knowledge/results.md`)
- [ ] **Closed-loop test**, one module at a time (C first): default gains (`kp`, `kd`, `kff` back to boot values: unplug/replug USB), `arm`, `pulse C=10`, `20`, `50`; note target vs measured peak and rise time → Claude compares with `knowledge/results.md`

## 3. 🟠 Motor drivers (ESCON Studio)
⚠️ Diagnostics and auto-tuning turn the motor: rope slack, nobody near, hand on the strip switch.
- [ ] Module A: Diagnostics (Hall test must pass) after its J3 recabling
- [ ] Module D: Diagnostics; upload its config as `escon/moduleD_back_<date>.edc`
- [ ] Always: USB in before 48 V on; 48 V off before USB out

## 4. 🟢 Software (Claude builds, you test)
API order: `docs/API.md`, `planned` sections. Each step: API.md first, simulator tests, then hardware.
- [ ] Step 2: **PTO**: perturb a set time after a foot strike (ms or % of stance), from gait events (simulated / replayed recorded trial until Vicon is connected)
- [ ] Step 3: **trials**: blocks, shuffle, 50–75 steps between perturbations, recovery stand-in (D8), baseline = first 3 s (D7), logs
- [ ] Step 4: **Vicon live** (force plates + markers) on the lab PC: needs the Vicon DataStream SDK there
- [ ] Validate `bumpem/gait.py` on a recorded MATLAB `Log_event_data_*.csv` (rule 5: before any live use). Need a recorded file from the lab
- [x] First web UI (`../BumpemUI/web`, served at http://127.0.0.1:8000/ui/): dial, perturbation, gait-phase picker, board settings, live force, STOP/Esc (2026-10-05, simulator)
- [ ] 🟢 You: `pip install -e ".[server,dev]"` once (adds `websockets`). **Motor check:** `bumpem serve --testing --board PORT` → http://127.0.0.1:8000/ → Pull each motor (5 N, 400 ms). **Production:** `bumpem serve --board PORT` → arm, perturb (closed loop only once the force readings are reliable)
- [ ] Give BumpemUI a GitHub remote
- [ ] Decide: firmware boots with `ch_D = 1` now that D works (firmware change → `PROTOCOL.md` first, re-flash)

## 5. 🟢 Hardware build
- [ ] 🔴 **Broken tower** (the thesis's out-of-service module; now unused). Diagnosis `docs/tests/broken-tower-diagnosis.md` (2026-10-05): **old 48 V supply faulty** (white residue leaking) → scrap; brake chopper passes all meter tests → bench test at 0.1 A before reuse; ESCON: input + phase 1 upper OK, finish 2b3–2b12; motor: section 3 to do. Amplifier: 4th IAA100 found (paired with a 200 kg, 1.0 mV/V DYMH-103): calibration check with 6 / 8 / 12 kg first; buy a 100 kg cell only if it fails (`docs/parts-to-buy.xlsx`). New RSP-2000-48 in hand: mains side by the university electrician only. New IAA100: copy a working module's DIP settings, trim to 0–3.3 V = 0–200 N
- [ ] 🟠 **Ropes** worn: measure rope diameter, drum diameter/width, eyebolt inner diameter; photo of worn spots and of the breakaway link → Claude proposes a low-stretch rope (Kevlar / Dyneema, ≥ ~2 kN, breakaway stays the weakest link). Lengths: Stanford guide p. 12 / 20 (drum rope = travel + 28 in, ≥ 3 wraps left at full travel)
- [ ] Carrier board (`hardware/carrier/README.md`): terminal orientation in KiCad's 3D viewer + 1:1 print check → order (makerspace can help) → solder → move modules over one at a time, re-run the open-loop test for each
- [ ] Module **B (front)**: is it planned? When mounted: trace cables, ESCON Diagnostics, open-loop test, `ch_B 1`

## Before final testing (not needed for preliminary tests)
- [ ] Module C config upload → `escon/moduleC_right_<date>.edc` → Claude compares with module A / Stanford. If gains equal the Stanford file (integral time 20000 µs) → load module A's file, then auto-tune C
- [ ] Every module: same base config + auto-tuning per driver (manual §4.3.1); upload each result into `escon/module<X>_<side>_<date>.edc`
- [ ] Screenshot the ESCON **firmware version** of each driver (look only, no update)
- [ ] Correct firmware `i_full` (9.9, setpoint 10 V = 30 A) and `kt` (0.231 Nm/A) (`knowledge/control.md`, `STATUS.md`)

## Scheduled
- [ ] 🟢 Call with the previous student, **week of 2026-10-05**: `QUESTIONS.md` (3.2 answered), bring the "Files to ask for" list (recorded MATLAB logs for step 4 above)

## Done
- [x] Mac: conda env `BumpemHome` (Python 3.12), `pip install -e ".[dev]" platformio`, pytest (2026-09-30)
- [x] 48 V chain of module C wired and checked: T0–T7 passed, shunt threshold > 48 V, e-stop pins found and contact type checked (2026-09-30)
- [x] Module C driver: supply and Hall wiring fixed, Diagnostics passed; module A config saved; all motors maxon 500267 (2026-10-01)
- [x] Teensy flashed with firmware v1, desk test passed, loopback wires removed (2026-09-29 / 10-02)
- [x] Breadboard recabled to ESCON-side colours (`docs/diagrams/cabling-4-modules.png`) (2026-10-02)
- [x] Open-loop tests passed: C, A (after fixing its swapped J3 Hall wires), A + C together, D (2026-10-02)
- [x] Server: board API, perturbation by angle, `bumpem perturb` (simulator) (2026-10-02)
- [x] Git: repo filtered, pushed to GitHub (`lore95/BumpemServer`) (2026-10-02)
- [x] Carrier board v1 designed: ERC / DRC / parity clean, spacing ≥ 0.74 mm (2026-10-02)

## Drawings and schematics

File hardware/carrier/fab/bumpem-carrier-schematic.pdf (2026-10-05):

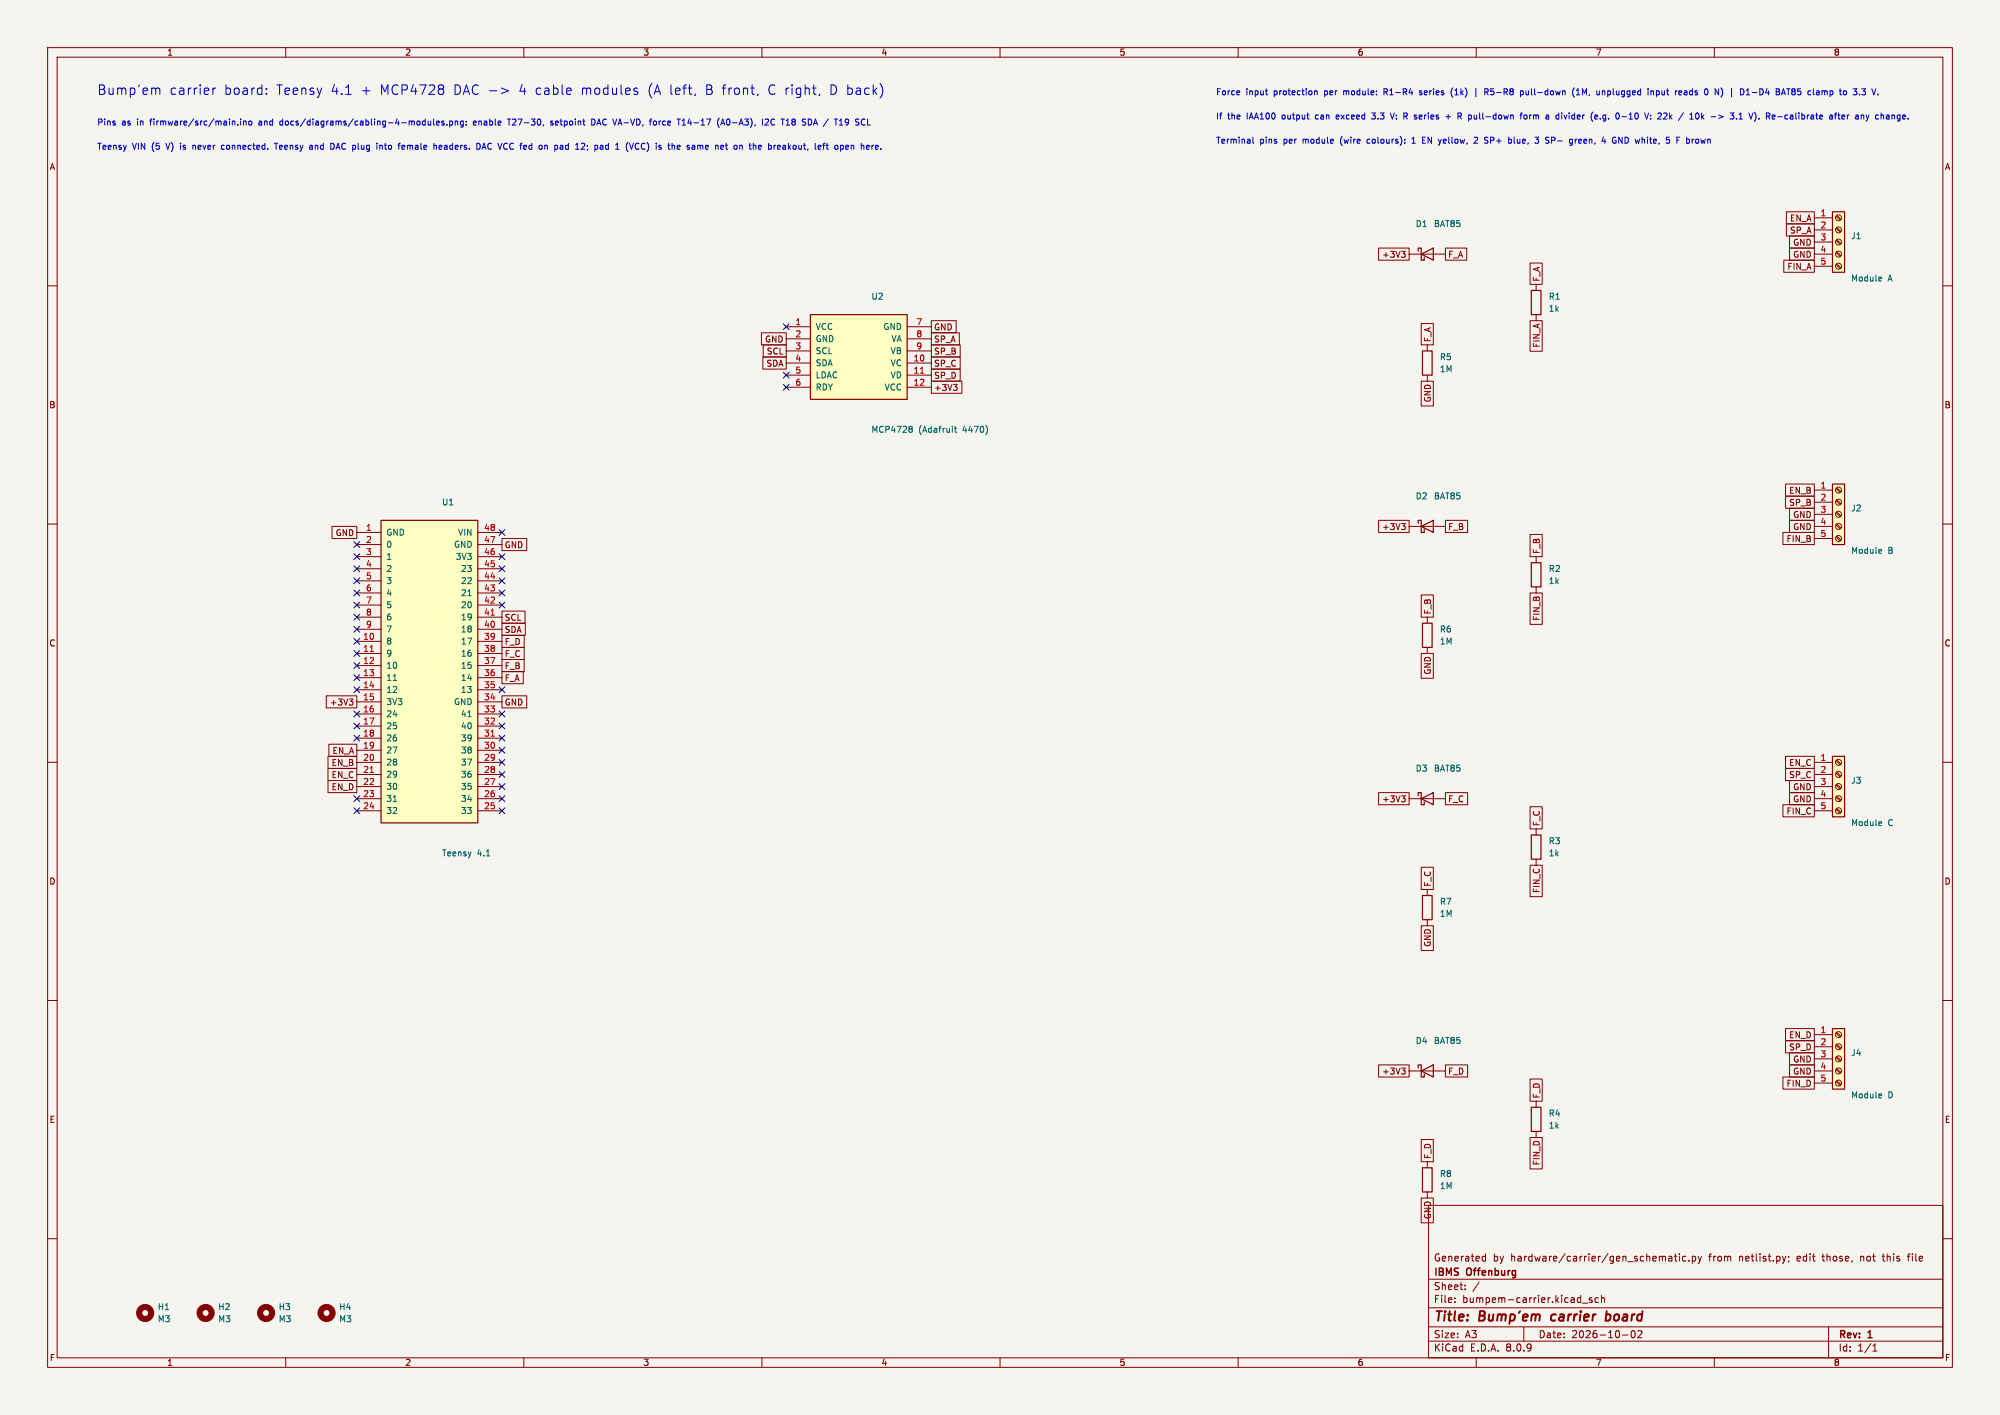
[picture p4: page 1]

Id: 1/1 Title: Bump'em carrier board

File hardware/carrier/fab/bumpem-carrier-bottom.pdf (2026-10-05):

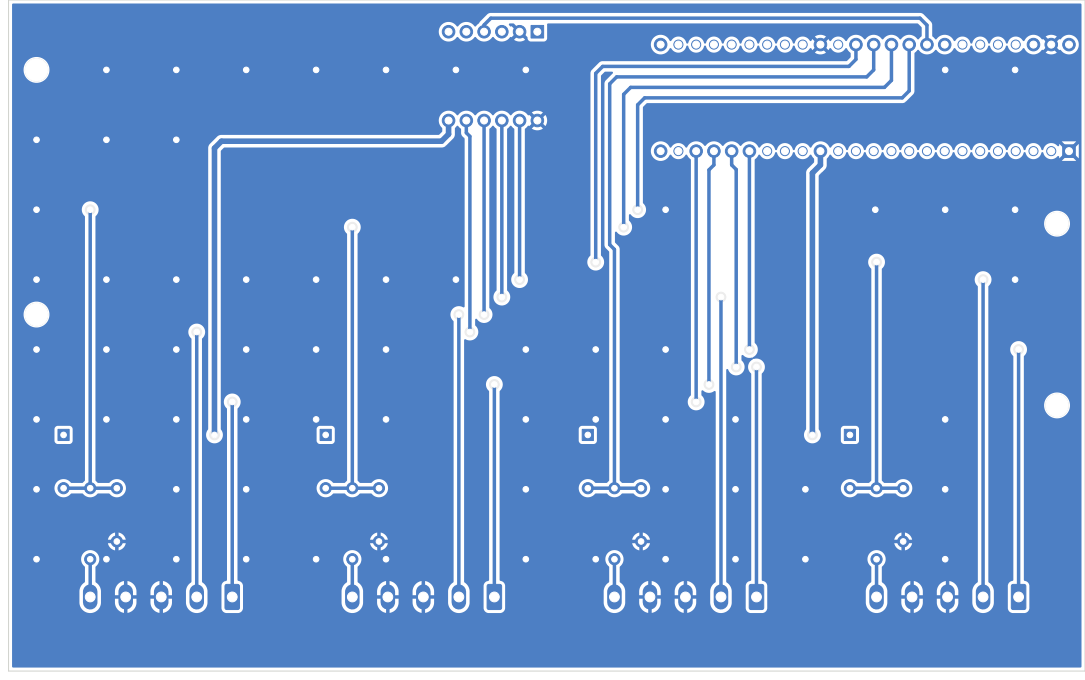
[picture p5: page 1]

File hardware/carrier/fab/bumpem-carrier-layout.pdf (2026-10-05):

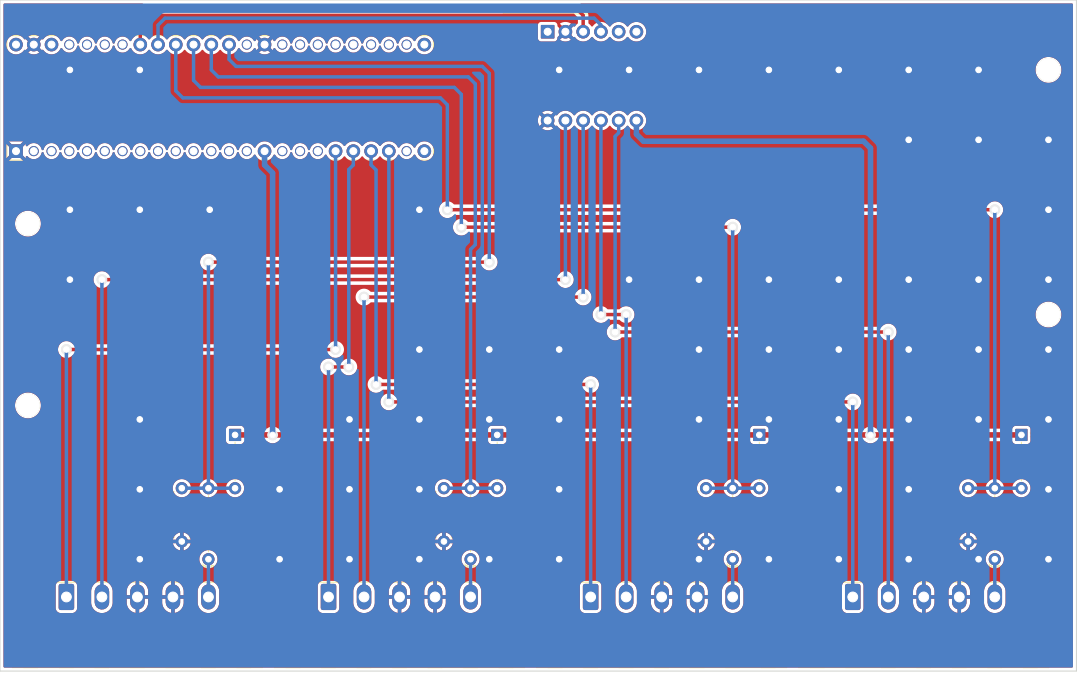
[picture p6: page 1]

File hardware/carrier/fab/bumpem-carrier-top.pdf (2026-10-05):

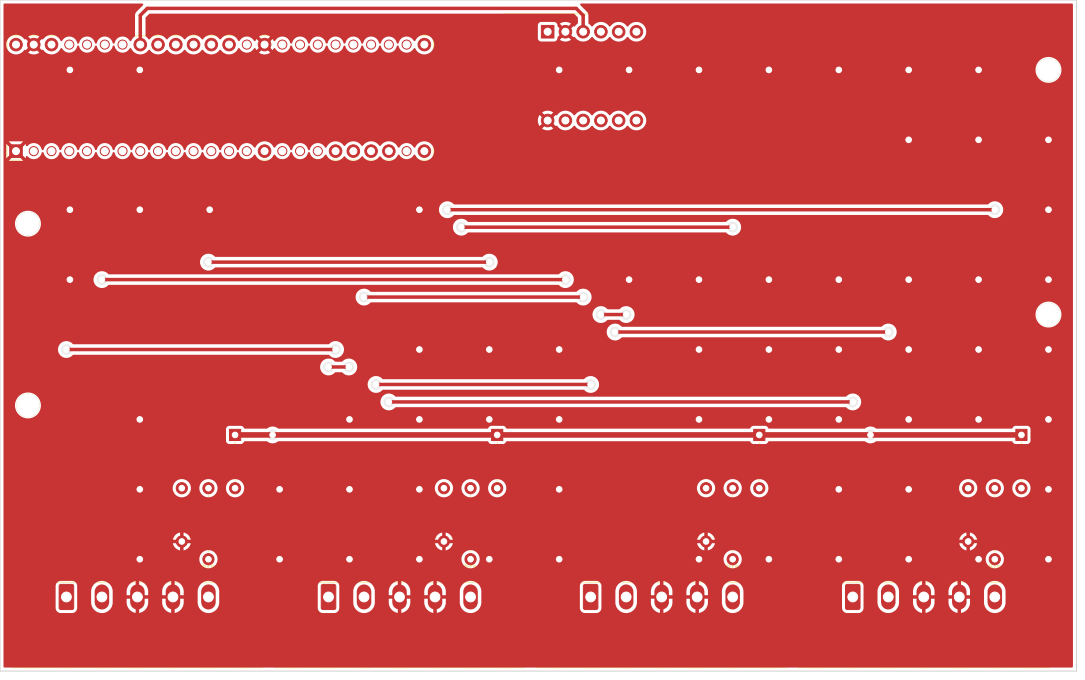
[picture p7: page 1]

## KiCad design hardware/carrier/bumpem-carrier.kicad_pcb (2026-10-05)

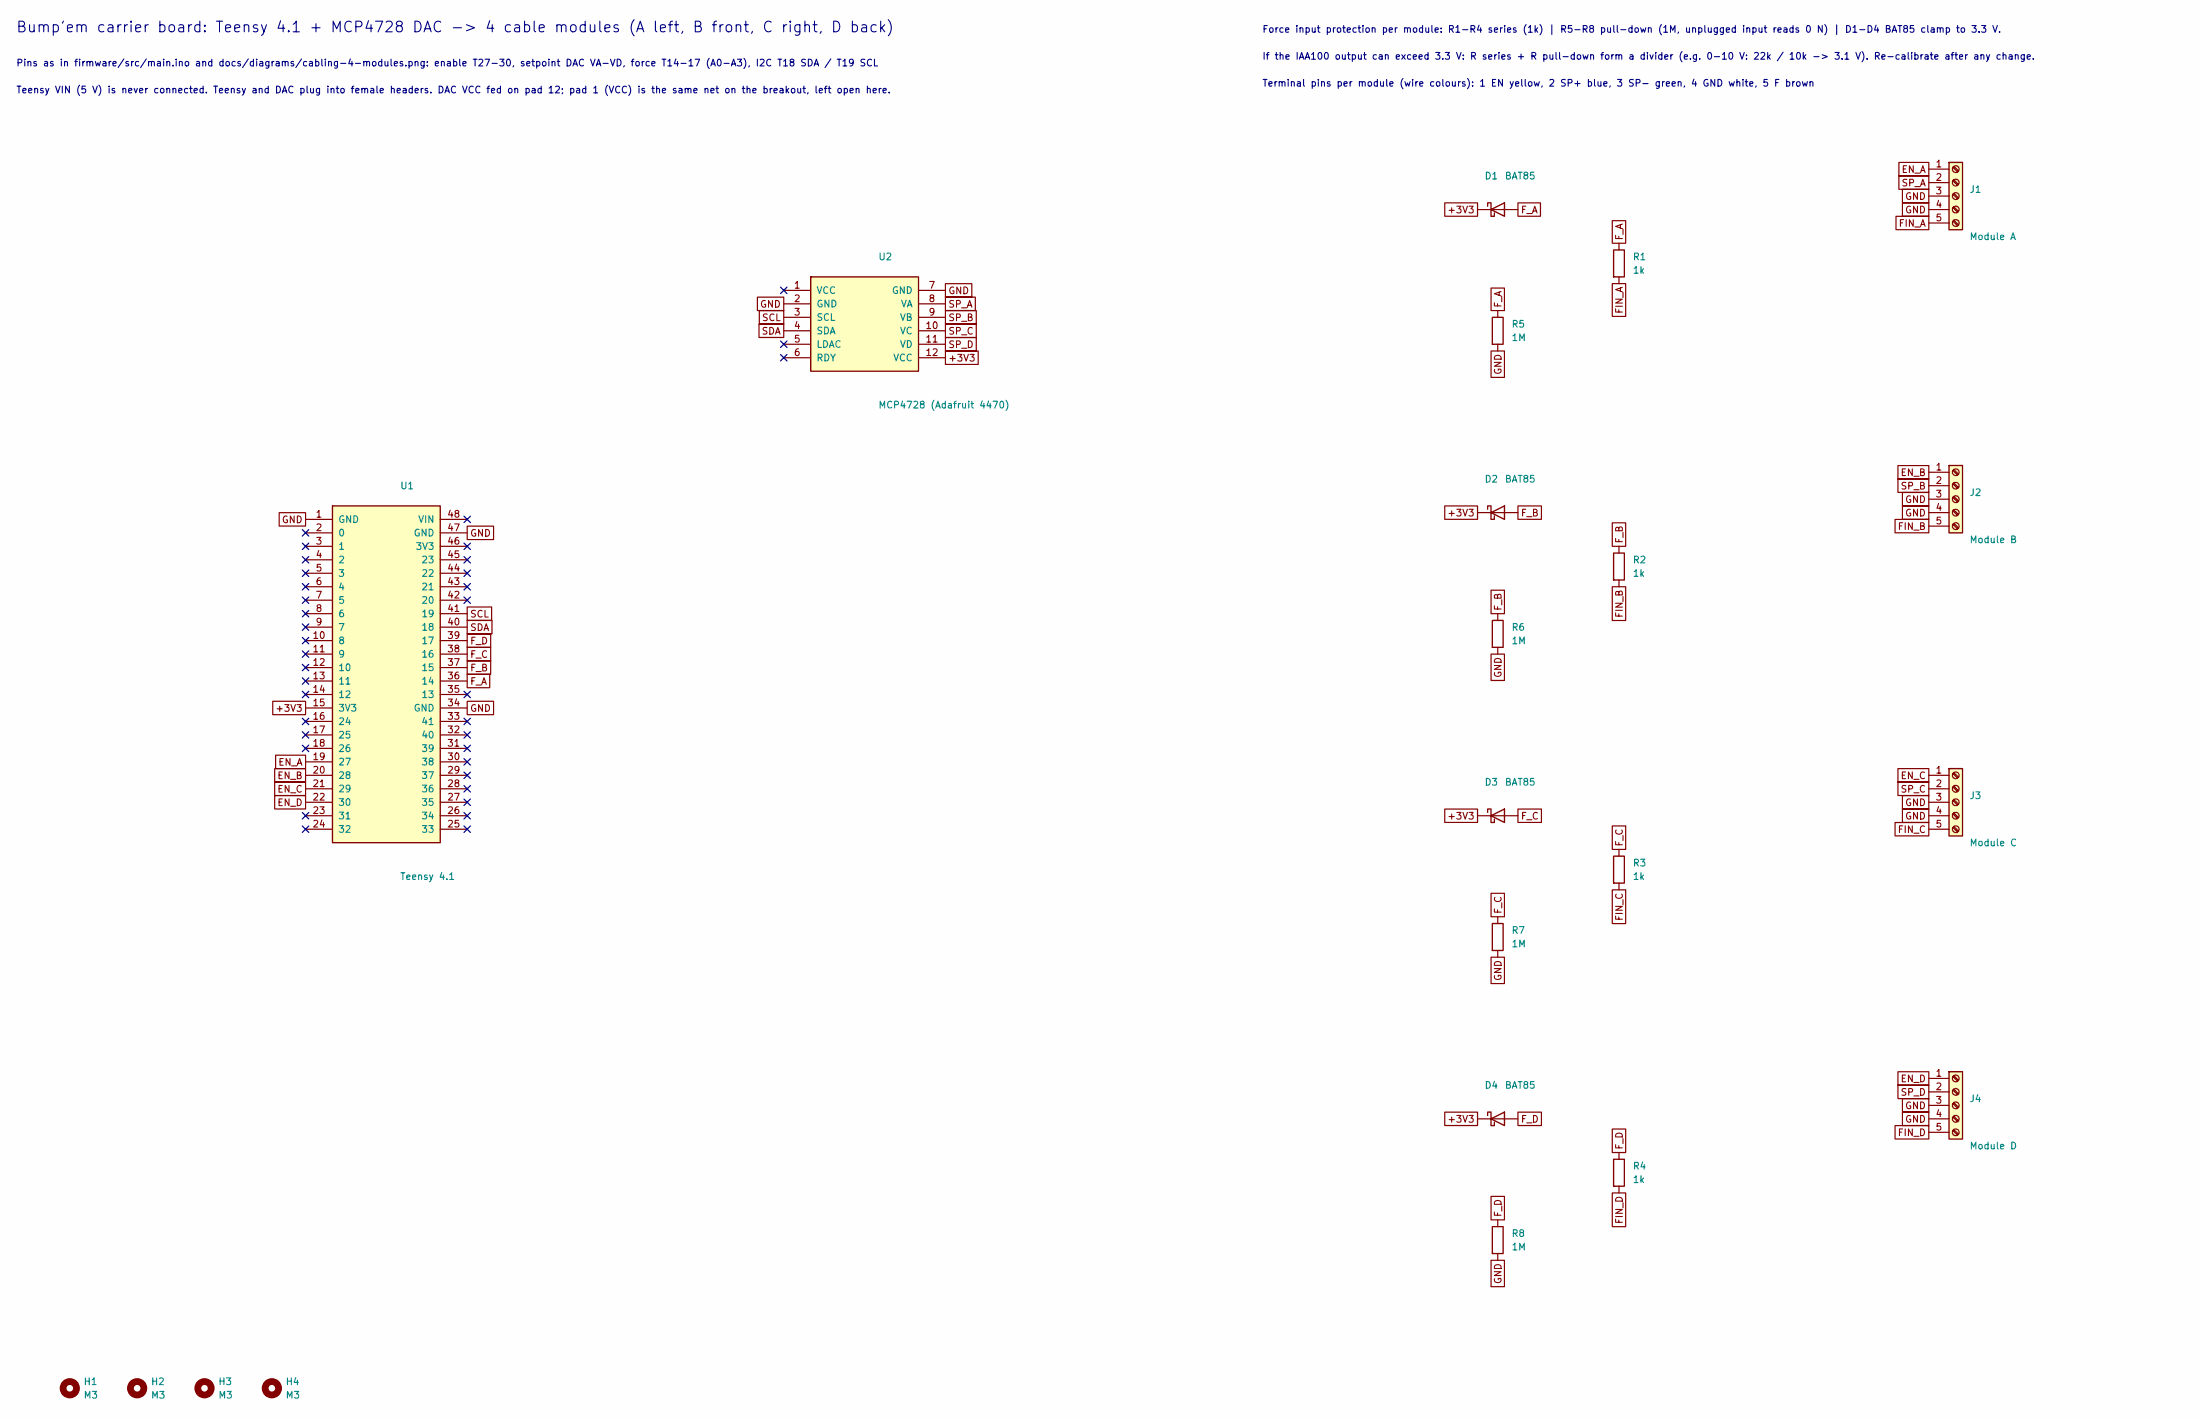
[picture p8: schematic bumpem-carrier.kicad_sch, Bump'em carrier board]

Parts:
D1, D2, D3, D4: BAT85; D_DO-35_SOD27_P7.62mm_Horizontal
H1, H2, H3, H4: M3; MountingHole_3.2mm_M3
J1: Module A; PhoenixContact_MSTB_2,5_5-GF-5,08_1x05_P5.08mm_Horizontal_T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
J2: Module B; PhoenixContact_MSTB_2,5_5-GF-5,08_1x05_P5.08mm_Horizontal_T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
J3: Module C; PhoenixContact_MSTB_2,5_5-GF-5,08_1x05_P5.08mm_Horizontal_T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
J4: Module D; PhoenixContact_MSTB_2,5_5-GF-5,08_1x05_P5.08mm_Horizontal_T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
R1, R2, R3, R4: 1k; R_Axial_DIN0207_L6.3mm_D2.5mm_P10.16mm_Horizontal
R5, R6, R7, R8: 1M; R_Axial_DIN0207_L6.3mm_D2.5mm_P7.62mm_Horizontal
U1: Teensy 4.1; Teensy41_Socket
U2: MCP4728 (Adafruit 4470); Adafruit_MCP4728_Socket

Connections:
+3V3: D1.1 (K), D2.1 (K), D3.1 (K), D4.1 (K), U1.15 (3V3), U2.12 (VCC)
EN_A: J1.1, U1.19 (27)
EN_B: J2.1, U1.20 (28)
EN_C: J3.1, U1.21 (29)
EN_D: J4.1, U1.22 (30)
FIN_A: J1.5, R1.2
FIN_B: J2.5, R2.2
FIN_C: J3.5, R3.2
FIN_D: J4.5, R4.2
F_A: D1.2 (A), R1.1, R5.1, U1.36 (14)
F_B: D2.2 (A), R2.1, R6.1, U1.37 (15)
F_C: D3.2 (A), R3.1, R7.1, U1.38 (16)
F_D: D4.2 (A), R4.1, R8.1, U1.39 (17)
GND: J1.3, J1.4, J2.3, J2.4, J3.3, J3.4, J4.3, J4.4, R5.2, R6.2, R7.2, R8.2, U1.1 (GND), U1.34 (GND), U1.47 (GND), U2.2 (GND), U2.7 (GND)
SCL: U1.41 (19), U2.3 (SCL)
SDA: U1.40 (18), U2.4 (SDA)
SP_A: J1.2, U2.8 (VA)
SP_B: J2.2, U2.9 (VB)
SP_C: J3.2, U2.10 (VC)
SP_D: J4.2, U2.11 (VD)

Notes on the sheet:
Bump'em carrier board: Teensy 4.1 + MCP4728 DAC -> 4 cable modules (A left, B front, C right, D back)
Pins as in firmware/src/main.ino and docs/diagrams/cabling-4-modules.png: enable T27-30, setpoint DAC VA-VD, force T14-17 (A0-A3), I2C T18 SDA / T19 SCL
Teensy VIN (5 V) is never connected. Teensy and DAC plug into female headers. DAC VCC fed on pad 12; pad 1 (VCC) is the same net on the breakout, left open here.
Force input protection per module: R1-R4 series (1k) | R5-R8 pull-down (1M, unplugged input reads 0 N) | D1-D4 BAT85 clamp to 3.3 V.
If the IAA100 output can exceed 3.3 V: R series + R pull-down form a divider (e.g. 0-10 V: 22k / 10k -> 3.1 V). Re-calibrate after any change.
Terminal pins per module (wire colours): 1 EN yellow, 2 SP+ blue, 3 SP- green, 4 GND white, 5 F brown

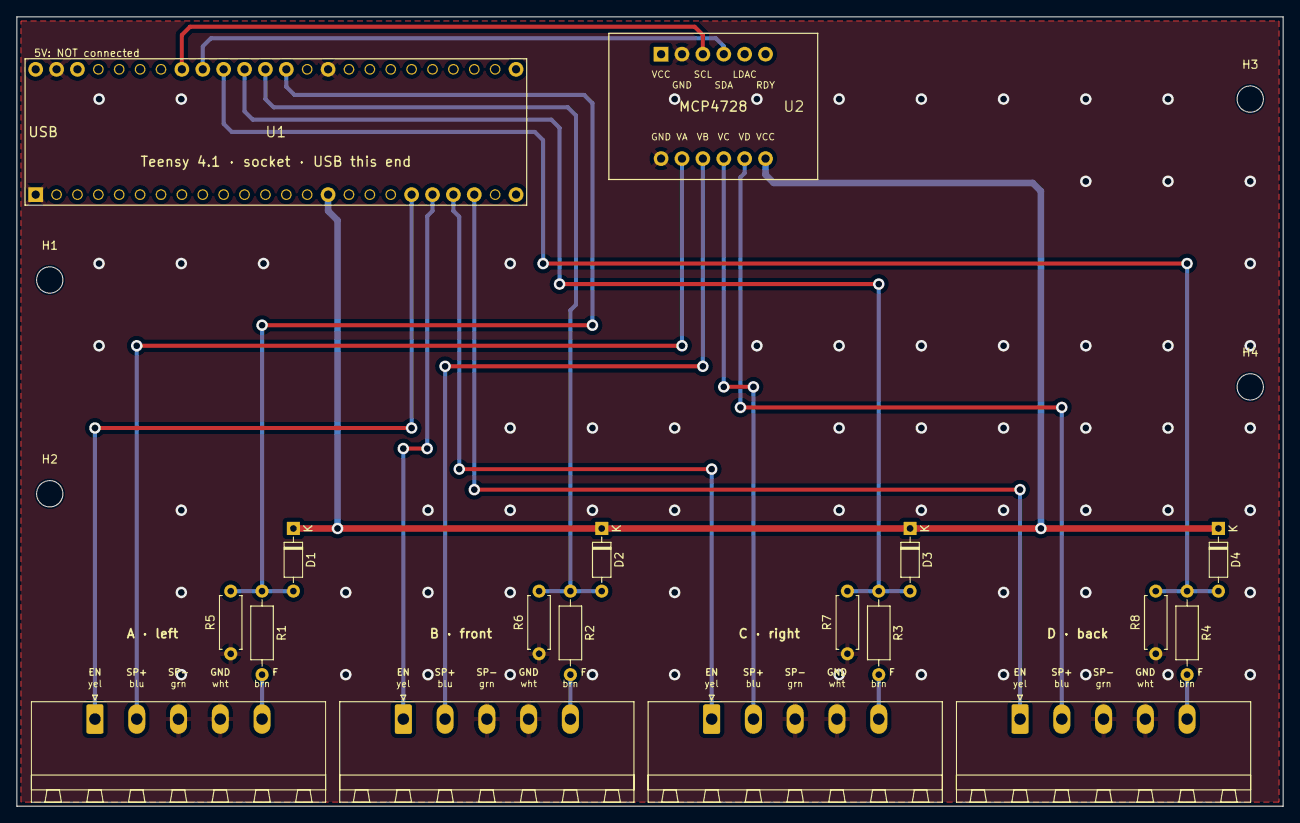
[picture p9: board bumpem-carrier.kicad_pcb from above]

Board: 2 copper layers, 154.0 x 96.0 mm, 22 parts (0 on the bottom side), 20 nets.

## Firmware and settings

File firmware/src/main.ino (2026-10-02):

/*************************************************************
 *  BUMP'EM FIRMWARE v1 — Teensy 4.1, 4 cable modules (A–D)
 *
 *  Serial protocol v1: docs/PROTOCOL.md (single source of truth).
 *  Parameter defaults reproduce the v0 firmware (legacy/Arduino_Script.ino).
 *
 *  The board knows channels, forces and times only. Angles, gait events,
 *  PTO and sequences are computed on the host.
 *************************************************************/

#include <Wire.h>
#include <Adafruit_MCP4728.h>

#define FW_VERSION  "1.0.0"
#define N_CH        4
#define F_HARD_MAX  200.0f    // N, ceiling for fmax_n (thesis §2.10)
#define ADC_MAX     1023.0f   // 10-bit (v0 .ino:39)
#define DAC_MAX     4095
#define D_WIN_MAX   8
#define LINE_MAX    128

Adafruit_MCP4728 Driver;

// ============================================================
//  CHANNELS (pins from v0 .ino:45-63, docs/knowledge/hardware.md)
// ============================================================
const char CH_NAME[N_CH]   = {'A', 'B', 'C', 'D'};
const int  PIN_FORCE[N_CH]  = {A0, A1, A2, A3};
const int  PIN_ENABLE[N_CH] = {27, 28, 29, 30};
const MCP4728_channel_t DAC_CH[N_CH] = {MCP4728_CHANNEL_A, MCP4728_CHANNEL_B,
                                        MCP4728_CHANNEL_C, MCP4728_CHANNEL_D};

// ============================================================
//  PARAMETERS (SET/GET). Defaults = v0.
// ============================================================
float loop_ms = 10, kp_track = 0.24, kd_track = 3.5, kp_pulse = 0.24, kd_pulse = 3.5;
float kff = 7.5, rc = 0.01905, kt = 0.1524, i_full = 30, f_full = 200;
float baseline_n = 5, fmax_n = 200, fault_n = 195, fault_ms = 20;
float filter_hz = 0, d_window = 1, arm_ms = 2000, pulse_max_ms = 1000;
float tel_div = 1, wd_ms = 0;
float ch_en[N_CH]  = {1, 1, 1, 0};           // D out of service
float cal_gain[N_CH] = {1, 1, 1, 1};
float cal_off[N_CH]  = {0, 0, 0, 0};

struct Param { const char *name; float *ptr; float lo, hi; bool disarmed_only; };
const Param PARAMS[] = {
  {"loop_ms", &loop_ms, 1, 50, true},
  {"kp_track", &kp_track, 0, 100, false}, {"kd_track", &kd_track, 0, 100, false},
  {"kp_pulse", &kp_pulse, 0, 100, false}, {"kd_pulse", &kd_pulse, 0, 100, false},
  {"kff", &kff, 0, 20, false}, {"rc", &rc, 0.001, 0.2, false}, {"kt", &kt, 0.001, 10, false},
  {"i_full", &i_full, 1, 100, false}, {"f_full", &f_full, 1, 1000, false},
  {"baseline_n", &baseline_n, 0, 30, false}, {"fmax_n", &fmax_n, 0, F_HARD_MAX, false},
  {"fault_n", &fault_n, 0, F_HARD_MAX, false}, {"fault_ms", &fault_ms, 1, 1000, false},
  {"filter_hz", &filter_hz, 0, 500, false}, {"d_window", &d_window, 1, D_WIN_MAX, false},
  {"arm_ms", &arm_ms, 0, 10000, false}, {"pulse_max_ms", &pulse_max_ms, 1, 5000, false},
  {"tel_div", &tel_div, 0, 1000, false}, {"wd_ms", &wd_ms, 0, 60000, false},
  {"ch_A", &ch_en[0], 0, 1, true}, {"ch_B", &ch_en[1], 0, 1, true},
  {"ch_C", &ch_en[2], 0, 1, true}, {"ch_D", &ch_en[3], 0, 1, true},
  {"gain_A", &cal_gain[0], 0.5, 2, false}, {"gain_B", &cal_gain[1], 0.5, 2, false},
  {"gain_C", &cal_gain[2], 0.5, 2, false}, {"gain_D", &cal_gain[3], 0.5, 2, false},
  {"offset_A", &cal_off[0], -20, 20, false}, {"offset_B", &cal_off[1], -20, 20, false},
  {"offset_C", &cal_off[2], -20, 20, false}, {"offset_D", &cal_off[3], -20, 20, false},
};
const int N_PARAMS = sizeof(PARAMS) / sizeof(PARAMS[0]);

// ============================================================
//  STATE
// ============================================================
enum State { DISARMED, ARMING, ARMED, FAULT, RELEASING, ESTOP };
const char *STATE_NAME[] = {"DISARMED", "ARMING", "ARMED", "FAULT", "RELEASING", "ESTOP"};
State state = DISARMED;

enum PulsePhase { P_NONE, P_PENDING, P_ACTIVE, P_ABORTING };
struct Pulse {
  PulsePhase phase;
  uint32_t id, t_start, t_abort;
  float delay, rise, dur, fall, amp[N_CH], abort_level[N_CH];
} pulse = {P_NONE};

// per-channel control state
float f_meas[N_CH], f_filt[N_CH], tgt[N_CH];
float f_hist[N_CH][D_WIN_MAX + 1];      // filtered force history for the D term
int   hist_n = 0;                        // valid samples in history
float bq_b0, bq_b1, bq_b2, bq_a1, bq_a2; // Butterworth coefficients
float bq_x1[N_CH], bq_x2[N_CH], bq_y1[N_CH], bq_y2[N_CH];
uint16_t dac[N_CH];
uint32_t fault_since[N_CH];

uint32_t ramp_t0; float ramp_ms, ramp_from;   // ARMING / RELEASING ramp
uint32_t last_rx_ms, loop_count;
uint32_t loop_us_max, overruns, tx_drops;
bool wd_tripped = false;
elapsedMicros since_tick;

char rx_buf[LINE_MAX]; int rx_len = 0;

// ============================================================
//  OUTPUT (never blocks the control loop for telemetry)
// ============================================================
char *fmt2(char *p, float x) {                 // fixed 2-decimal float, no printf float needed
  long v = lroundf(x * 100.0f);
  if (v < 0) { *p++ = '-'; v = -v; }
  p += sprintf(p, "%ld.%02ld", v / 100, v % 100);
  return p;
}

void emit(const char *line, bool droppable) {
  int n = strlen(line) + 2;
  if (droppable && Serial.availableForWrite() < n) { tx_drops++; return; }
  Serial.print(line); Serial.print("\r\n");
}

void ack_ok(const char *cmd, const char *detail = nullptr) {
  char b[LINE_MAX];
  snprintf(b, sizeof b, detail ? "A,OK,%s,%s" : "A,OK,%s", cmd, detail);
  emit(b, false);
}
void ack_err(const char *cmd, const char *reason) {
  char b[LINE_MAX];
  snprintf(b, sizeof b, "A,ERR,%s,%s", cmd, reason);
  emit(b, false);
}
void event(const char *kind, const char *rest = nullptr) {
  char b[LINE_MAX];
  snprintf(b, sizeof b, rest ? "E,%lu,%s,%s" : "E,%lu,%s", (unsigned long)millis(), kind, rest);
  emit(b, true);                        // may be called mid-loop: never block
}

void set_state(State s) {
  if (s == state) return;
  state = s;
  event("STATE", STATE_NAME[s]);
}

// ============================================================
//  HARDWARE
// ============================================================
void write_outputs() {
  Driver.fastWrite(dac[0], dac[1], dac[2], dac[3]);  // one I²C transaction for all channels
}

void drivers_off() {
  for (int c = 0; c < N_CH; c++) { digitalWrite(PIN_ENABLE[c], LOW); dac[c] = 0; }
  write_outputs();
}

// ============================================================
//  FILTER / CONTROL
// ============================================================
void filter_setup() {
  if (filter_hz <= 0) return;
  float K = tanf(PI * filter_hz * loop_ms / 1000.0f), K2 = K * K;
  float norm = 1.0f / (1.0f + M_SQRT2 * K + K2);
  bq_b0 = K2 * norm; bq_b1 = 2 * bq_b0; bq_b2 = bq_b0;
  bq_a1 = 2 * (K2 - 1) * norm; bq_a2 = (1 - M_SQRT2 * K + K2) * norm;
}

void control_reset() {           // restart filter and D history from the current reading
  for (int c = 0; c < N_CH; c++) {
    float r = analogRead(PIN_FORCE[c]) / ADC_MAX * f_full * cal_gain[c] + cal_off[c];
    bq_x1[c] = bq_x2[c] = bq_y1[c] = bq_y2[c] = r;
    for (int k = 0; k <= D_WIN_MAX; k++) f_hist[c][k] = r;
  }
  hist_n = D_WIN_MAX + 1;
  filter_setup();
}

float filter_step(int c, float x) {
  if (filter_hz <= 0) return x;
  float y = bq_b0 * x + bq_b1 * bq_x1[c] + bq_b2 * bq_x2[c] - bq_a1 * bq_y1[c] - bq_a2 * bq_y2[c];
  bq_x2[c] = bq_x1[c]; bq_x1[c] = x; bq_y2[c] = bq_y1[c]; bq_y1[c] = y;
  return y;
}

bool pulse_drives_gains() { return pulse.phase == P_ACTIVE || pulse.phase == P_ABORTING; }

// Pulse amplitude contribution on channel c at time now (0 outside a pulse)
float pulse_amp(int c, uint32_t now) {
  if (pulse.phase == P_ACTIVE) {
    float e = now - pulse.t_start, a = pulse.amp[c];
    if (e < pulse.rise) return a * e / pulse.rise;
    if (e < pulse.dur - pulse.fall) return a;
    if (e < pulse.dur) return a * (pulse.dur - e) / pulse.fall;
    return 0;
  }
  if (pulse.phase == P_ABORTING) {
    float e = now - pulse.t_abort;
    if (pulse.fall <= 0 || e >= pulse.fall) return 0;
    return pulse.abort_level[c] * (1 - e / pulse.fall);
  }
  return 0;
}

void pulse_update(uint32_t now) {
  char id[16]; snprintf(id, sizeof id, "%lu", (unsigned long)pulse.id);
  if (pulse.phase == P_PENDING && (int32_t)(now - pulse.t_start) >= 0) {
    pulse.phase = P_ACTIVE;
    event("PSTART", id);
  }
  if (pulse.phase == P_ACTIVE && now - pulse.t_start >= pulse.dur) {
    pulse.phase = P_NONE;
    event("PEND", id);
  }
  if (pulse.phase == P_ABORTING && (pulse.fall <= 0 || now - pulse.t_abort >= pulse.fall)) {
    pulse.phase = P_NONE;
  }
}

void pulse_abort(uint32_t now) {
  if (pulse.phase == P_NONE || pulse.phase == P_ABORTING) return;
  char id[16]; snprintf(id, sizeof id, "%lu", (unsigned long)pulse.id);
  if (pulse.phase == P_ACTIVE) {
    for (int c = 0; c < N_CH; c++) pulse.abort_level[c] = pulse_amp(c, now);
    pulse.t_abort = now;
    pulse.phase = P_ABORTING;
  } else {
    pulse.phase = P_NONE;
  }
  event("PABORT", id);
}

// Baseline level for the current state (ARMING/RELEASING ramps)
float state_level(uint32_t now) {
  switch (state) {
    case ARMED: case FAULT: return baseline_n;
    case ARMING: case RELEASING: {
      float e = now - ramp_t0;
      float to = (state == ARMING) ? baseline_n : 0;
      if (ramp_ms <= 0 || e >= ramp_ms) return to;
      return ramp_from + (to - ramp_from) * e / ramp_ms;
    }
    default: return 0;
  }
}

void control_step(uint32_t now) {
  int m = (int)d_window;
  bool in_pulse = pulse_drives_gains();
  float kp = in_pulse ? kp_pulse : kp_track, kd = in_pulse ? kd_pulse : kd_track;
  float level = state_level(now);
  bool driving = (state == ARMED || state == FAULT || state == ARMING || state == RELEASING);

  for (int c = 0; c < N_CH; c++) {
    f_meas[c] = analogRead(PIN_FORCE[c]) / ADC_MAX * f_full * cal_gain[c] + cal_off[c];
    f_filt[c] = filter_step(c, f_meas[c]);
    for (int k = D_WIN_MAX; k > 0; k--) f_hist[c][k] = f_hist[c][k - 1];
    f_hist[c][0] = f_filt[c];

    if (!driving || ch_en[c] < 0.5f) {
      tgt[c] = 0; dac[c] = 0;
      digitalWrite(PIN_ENABLE[c], LOW);
      continue;
    }
    tgt[c] = min(level + pulse_amp(c, now), fmax_n);     // firmware clamp, whatever the host sends

    float d = (f_filt[c] - f_hist[c][m]) / (m * loop_ms);  // N/ms, as v0
    float ides = kp * (tgt[c] - f_filt[c]) - kd * d + kff * tgt[c] * rc / kt;
    float u = constrain(ides / i_full, 0.0f, 1.0f);
    dac[c] = (uint16_t)(u * DAC_MAX);
    digitalWrite(PIN_ENABLE[c], HIGH);

    // over-force fault
    if (fault_n > 0 && f_meas[c] >= fault_n) {
      if (!fault_since[c]) fault_since[c] = now ? now : 1;
      else if (now - fault_since[c] >= fault_ms && state == ARMED) {
        pulse_abort(now);
        char b[32]; char *p = b + sprintf(b, "%c,", CH_NAME[c]); fmt2(p, f_meas[c]);
        event("FAULT", b);
        set_state(FAULT);
      }
    } else {
      fault_since[c] = 0;
    }
  }
  write_outputs();

  if (state == ARMING && now - ramp_t0 >= ramp_ms) set_state(ARMED);
  if (state == RELEASING && now - ramp_t0 >= ramp_ms) { drivers_off(); set_state(DISARMED); }
}

void telemetry(uint32_t now) {
  if (tel_div < 1 || loop_count % (uint32_t)tel_div) return;
  char b[256]; char *p = b;
  p += sprintf(p, "T,%lu,%s,%lu", (unsigned long)now, STATE_NAME[state],
               (unsigned long)(pulse.phase == P_NONE ? 0 : pulse.id));
  for (int c = 0; c < N_CH; c++) {
    *p++ = ','; p = fmt2(p, tgt[c]);
    *p++ = ','; p = fmt2(p, f_meas[c]);
    p += sprintf(p, ",%u", dac[c]);
  }
  *p = 0;
  emit(b, true);
}

// ============================================================
//  COMMANDS
// ============================================================
int split(char *s, char **tok, int max) {
  int n = 0;
  for (char *t = strtok(s, " \t"); t && n < max; t = strtok(nullptr, " \t")) tok[n++] = t;
  return n;
}

bool parse_num(const char *s, float *out) {
  char *end; *out = strtof(s, &end);
  return end != s && *end == 0;
}

void upcase(char *s) { for (; *s; s++) *s = toupper(*s); }

const Param *find_param(const char *name) {
  for (int i = 0; i < N_PARAMS; i++) if (!strcasecmp(PARAMS[i].name, name)) return &PARAMS[i];
  return nullptr;
}

void print_param(const Param *p) {
  char b[64]; char *q = b + sprintf(b, "P,%s,", p->name);
  dtostrf(*p->ptr, 0, 5, q);            // 5 decimals: enough for rc/kt
  emit(b, false);
}

void cmd_pulse(char **tok, int n, uint32_t now) {
  if (n != 10) { ack_err("PULSE", "usage: PULSE id delay rise dur fall aA aB aC aD"); return; }
  if (state != ARMED) { ack_err("PULSE", "not armed"); return; }
  if (pulse.phase != P_NONE) { ack_err("PULSE", "busy"); return; }
  float v[9];
  for (int i = 0; i < 9; i++) if (!parse_num(tok[i + 1], &v[i])) { ack_err("PULSE", "bad number"); return; }
  float delay = v[1], rise = v[2], dur = v[3], fall = v[4];
  if (v[0] < 1) { ack_err("PULSE", "id must be >= 1"); return; }
  if (delay < 0 || delay > 10000) { ack_err("PULSE", "delay out of range"); return; }
  if (rise < 0 || fall < 0 || dur <= 0 || rise + fall > dur) { ack_err("PULSE", "need rise+fall <= dur"); return; }
  if (dur > pulse_max_ms) { ack_err("PULSE", "dur > pulse_max_ms"); return; }
  for (int c = 0; c < N_CH; c++) {
    float a = v[5 + c];
    if (a < 0) { ack_err("PULSE", "negative amplitude"); return; }
    if (a > 0 && ch_en[c] < 0.5f) { ack_err("PULSE", "channel disabled"); return; }
    if (baseline_n + a > fmax_n) { ack_err("PULSE", "exceeds fmax_n"); return; }
  }
  pulse.id = (uint32_t)v[0];
  pulse.delay = delay; pulse.rise = rise; pulse.dur = dur; pulse.fall = fall;
  for (int c = 0; c < N_CH; c++) pulse.amp[c] = v[5 + c];
  pulse.t_start = now + (uint32_t)delay;
  pulse.phase = P_PENDING;
  char d[16]; snprintf(d, sizeof d, "%lu", (unsigned long)pulse.id);
  ack_ok("PULSE", d);
}

void handle_line(char *line, uint32_t now) {
  char *tok[12];
  int n = split(line, tok, 12);
  if (n == 0) return;
  upcase(tok[0]);
  const char *cmd = tok[0];

  if (!strcmp(cmd, "PING")) { ack_ok(cmd); }
  else if (!strcmp(cmd, "INFO")) {
    char b[LINE_MAX];
    snprintf(b, sizeof b, "I,proto=1,fw=%s,board=teensy41,channels=%d,f_hard_max=200", FW_VERSION, N_CH);
    emit(b, false); ack_ok(cmd);
  }
  else if (!strcmp(cmd, "STATS")) {
    char b[LINE_MAX];
    snprintf(b, sizeof b, "I,loop_us_max=%lu,overruns=%lu,tx_drops=%lu,uptime_ms=%lu",
             (unsigned long)loop_us_max, (unsigned long)overruns, (unsigned long)tx_drops,
             (unsigned long)millis());
    emit(b, false); loop_us_max = 0; ack_ok(cmd);
  }
  else if (!strcmp(cmd, "GET")) {
    if (n == 1) { for (int i = 0; i < N_PARAMS; i++) print_param(&PARAMS[i]); ack_ok(cmd); }
    else {
      const Param *p = find_param(tok[1]);
      if (!p) { ack_err(cmd, "unknown parameter"); return; }
      print_param(p); ack_ok(cmd);
    }
  }
  else if (!strcmp(cmd, "SET")) {
    if (n != 3) { ack_err(cmd, "usage: SET name value"); return; }
    const Param *p = find_param(tok[1]);
    float v;
    if (!p) { ack_err(cmd, "unknown parameter"); return; }
    if (!parse_num(tok[2], &v)) { ack_err(cmd, "bad number"); return; }
    if (v < p->lo || v > p->hi) { ack_err(cmd, "out of range"); return; }
    if (pulse.phase != P_NONE) { ack_err(cmd, "busy"); return; }
    if (state == ARMING || state == RELEASING) { ack_err(cmd, "busy"); return; }
    if (p->disarmed_only && !(state == DISARMED || state == ESTOP)) { ack_err(cmd, "disarm first"); return; }
    if (p->ptr == &filter_hz && v > 0 && v >= 500.0f / loop_ms) { ack_err(cmd, "filter_hz >= Nyquist"); return; }
    if (p->ptr == &loop_ms && filter_hz > 0 && filter_hz >= 500.0f / v) { ack_err(cmd, "filter_hz >= Nyquist"); return; }
    if (p->ptr == &d_window || p->ptr == &loop_ms || p->ptr == &tel_div) v = roundf(v);
    if ((p->ptr == &baseline_n && v > fmax_n) || (p->ptr == &fmax_n && v < baseline_n)) { ack_err(cmd, "baseline_n > fmax_n"); return; }
    *p->ptr = v;
    if (p->ptr == &filter_hz || p->ptr == &loop_ms) control_reset();
    ack_ok(cmd, p->name);
  }
  else if (!strcmp(cmd, "ARM")) {
    if (state != DISARMED && state != ESTOP) { ack_err(cmd, "already armed"); return; }
    control_reset();
    ramp_t0 = now; ramp_ms = arm_ms; ramp_from = 0;
    set_state(ARMING); ack_ok(cmd);
  }
  else if (!strcmp(cmd, "PULSE")) { cmd_pulse(tok, n, now); }
  else if (!strcmp(cmd, "ABORT")) { pulse_abort(now); ack_ok(cmd); }
  else if (!strcmp(cmd, "RELEASE")) {
    float ms = 1000;
    if (n > 1 && (!parse_num(tok[1], &ms) || ms < 0 || ms > 10000)) { ack_err(cmd, "bad ms"); return; }
    if (state != ARMED && state != FAULT) { ack_err(cmd, "not armed"); return; }
    pulse_abort(now);                   // active pulse ramps down over its fall while releasing
    ramp_from = baseline_n; ramp_t0 = now; ramp_ms = ms;
    set_state(RELEASING); ack_ok(cmd);
  }
  else if (!strcmp(cmd, "ESTOP") || !strcmp(cmd, "STOP")) {
    drivers_off();
    if (pulse.phase != P_NONE) pulse_abort(now);
    pulse.phase = P_NONE;
    set_state(ESTOP); ack_ok("ESTOP");
  }
  else if (!strcmp(cmd, "CLEAR")) {
    if (state != FAULT) { ack_err(cmd, "not in fault"); return; }
    set_state(ARMED); ack_ok(cmd);
  }
  else { ack_err(cmd, "unknown command"); }
}

void read_serial(uint32_t now) {
  while (Serial.available()) {
    char ch = Serial.read();
    if (ch == '\r') continue;
    if (ch == '\n') {
      rx_buf[rx_len] = 0;
      last_rx_ms = now; wd_tripped = false;
      handle_line(rx_buf, now);
      rx_len = 0;
    } else if (rx_len < LINE_MAX - 1) {
      rx_buf[rx_len++] = ch;
    } else {
      rx_len = 0;                       // overlong line: discard
      ack_err("LINE", "too long");
    }
  }
}

// ============================================================
//  SETUP / LOOP
// ============================================================
void setup() {
  Serial.begin(115200);
  for (int c = 0; c < N_CH; c++) { pinMode(PIN_ENABLE[c], OUTPUT); digitalWrite(PIN_ENABLE[c], LOW); }

  Wire.begin();
  Wire.setClock(400000);
  if (!Driver.begin()) {
    // Cannot drive motors; report forever, drivers stay disabled.
    while (1) { Serial.println("E,0,FAULT,DAC init failed"); delay(1000); }
  }
  for (int c = 0; c < N_CH; c++) Driver.setChannelValue(DAC_CH[c], 0);  // sets VREF=VDD, gain 1x (as v0)
  drivers_off();
  control_reset();
  last_rx_ms = millis();
  emit("I,proto=1,fw=" FW_VERSION ",board=teensy41,channels=4,f_hard_max=200", false);
  event("STATE", STATE_NAME[state]);
}

void loop() {
  uint32_t now = millis();
  read_serial(now);

  // watchdog: host silent → abort any pulse, keep tension (safety.md)
  if (wd_ms > 0 && !wd_tripped && now - last_rx_ms > wd_ms) {
    wd_tripped = true;
    pulse_abort(now);
    event("WD");
  }

  uint32_t period_us = (uint32_t)loop_ms * 1000;
  if (since_tick < period_us) return;
  if (since_tick >= 2 * period_us) { overruns++; since_tick = 0; }
  else since_tick -= period_us;

  elapsedMicros busy;
  now = millis();
  pulse_update(now);
  control_step(now);
  telemetry(now);
  loop_count++;
  if (busy > loop_us_max) loop_us_max = busy;
}

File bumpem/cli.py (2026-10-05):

"""`bumpem` command-line entry point (protocol v1)."""
from __future__ import annotations

import argparse
import sys
import time
from pathlib import Path

from . import protocol as P
from .device import Board, BoardError


def _open(args) -> Board:
    if args.sim:
        from .sim import SimLink
        return Board(SimLink())
    if not args.port:
        sys.exit("--port or --sim required (see `bumpem ports`)")
    from .device import SerialLink
    try:
        return Board(SerialLink(args.port))
    except Exception as e:     # busy port, wrong name, unplugged
        sys.exit(f"cannot open {args.port}: {e}")


def _amps(items: list[str]) -> dict[str, float]:
    out = {}
    for it in items:
        ch, _, val = it.partition("=")
        out[ch.upper()] = float(val)
    return out


def _print(msg) -> None:
    if isinstance(msg, P.Telemetry):
        cols = "  ".join(f"{c} {msg.target[c]:6.1f}/{msg.measured[c]:6.1f}" for c in P.CHANNELS)
        print(f"{msg.t_ms:>9} {msg.state:<9} {cols}")
    elif isinstance(msg, P.Event):
        print(f"{msg.t_ms:>9} ** {msg.kind} {' '.join(msg.args)}")
    elif isinstance(msg, str) and msg:
        print(f"# {msg}")


def main(argv=None):
    ap = argparse.ArgumentParser(prog="bumpem")
    sub = ap.add_subparsers(dest="cmd", required=True)
    sub.add_parser("ports", help="list serial ports")
    specs = {
        "info": "board info", "get": "read parameters", "set": "set a parameter",
        "arm": "enable drivers, ramp to baseline", "pulse": "one pulse (amplitudes relative to baseline)",
        "perturb": "one pulse by direction: 0 front, +90 left, -90 right, 180 back (split over the cables)",
        "abort": "cancel pulse", "release": "ramp to 0 and disable (stop treadmill first)",
        "estop": "drivers off now (stop treadmill first)", "clear": "clear FAULT",
        "stats": "loop timing", "monitor": "print telemetry and events",
    }
    for name, help_ in specs.items():
        p = sub.add_parser(name, help=help_)
        p.add_argument("--port")
        p.add_argument("--sim", action="store_true")
        if name == "get":
            p.add_argument("name", nargs="?")
        if name == "set":
            p.add_argument("name")
            p.add_argument("value", type=float)
        if name == "release":
            p.add_argument("--ms", type=float, default=1000)
        if name == "pulse":
            p.add_argument("amps", nargs="+", help="e.g. A=95  or  A=65.7 B=65.7")
            p.add_argument("--id", type=int, default=int(time.time()) % 1_000_000 + 1)
            p.add_argument("--delay", type=float, default=0)
            p.add_argument("--rise", type=float, default=50)
            p.add_argument("--dur", type=float, default=600)
            p.add_argument("--fall", type=float, default=0)
        if name == "perturb":
            p.add_argument("angle", type=float, help="pull direction in degrees (Vicon axes)")
            p.add_argument("amplitude", type=float, help="resultant force above baseline, N")
            p.add_argument("--id", type=int, default=int(time.time()) % 1_000_000 + 1)
            p.add_argument("--delay", type=float, default=0)
            p.add_argument("--phase1", type=float, default=50, help="ramp up, ms")
            p.add_argument("--dur", type=float, default=600, help="start to end incl. ramps, ms")
            p.add_argument("--phase2", type=float, default=0, help="ramp down, ms")
        if name in ("pulse", "perturb", "arm"):
            p.add_argument("--watch", type=float, default=0, help="then monitor for N seconds")
    sv = sub.add_parser("serve", help="HTTP/WebSocket API server (docs/API.md); test page at /docs")
    sv.add_argument("--host", default="127.0.0.1")
    sv.add_argument("--port", type=int, default=8000, help="HTTP port")
    sv.add_argument("--board", help="serial device to connect at startup, or 'sim'")
    sv.add_argument("--wd-ms", type=int, default=1000, help="board watchdog while served (0 = off)")
    mg = sv.add_mutually_exclusive_group()
    mg.add_argument("--testing", action="store_const", const="testing", dest="mode",
                    help="testing UI: one pull per motor, no arming (docs/API.md Modes)")
    mg.add_argument("--production", action="store_const", const="production", dest="mode",
                    help="production UI: arm, perturbations, force feedback (default)")
    sv.set_defaults(mode="production")
    sv.add_argument("--modules", default="ACD",
                    help="mounted modules: their channels are switched on at connect, the others off "
                         "(default ACD = setup 2026-10-02; \"\" = keep firmware defaults)")
    sv.add_argument("--ui", default=str(Path(__file__).resolve().parents[2] / "BumpemUI" / "web"),
                    help="browser UI folder, served at /ui/ (default: ../BumpemUI/web)")
    args = ap.parse_args(argv)

    if args.cmd == "serve":
        try:
            import uvicorn
            from .server import create_app
        except ImportError:
            sys.exit('server extras missing: pip install -e ".[server]"')
        page = "/ui/testing.html" if args.mode == "testing" else "/ui/"
        print(f"bumpem server ({args.mode} mode) on http://{args.host}:{args.port}  (UI: {page}, API test page: /docs)")
        uvicorn.run(create_app(wd_ms=args.wd_ms, board=args.board, ui_dir=args.ui, modules=args.modules or None,
                               mode=args.mode),
                    host=args.host, port=args.port)
        return

    if args.cmd == "ports":
        from .device import find_ports
        print("\n".join(find_ports()) or "no ports found")
        return
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

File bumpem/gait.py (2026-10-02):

"""Foot-strike / toe-off detection. Exact port of legacy/MATLAB_script.m (lines 83-125).

Feed one sample at a time: event = det.update(t_s, fz_total).
"""
from __future__ import annotations

from dataclasses import dataclass, field

FS_VALID, FS_NOISE, TO_VALID, TO_NOISE = "FS_VALID", "FS_NOISE", "TO_VALID", "TO_NOISE"


@dataclass
class GaitParams:
    fz_threshold: float = 250.0     # N        (MATLAB :5)
    min_gait_cycle: float = 0.30    # s        (MATLAB :6)
    min_stance: float = 0.15        # s        (MATLAB :7)
    min_since_to: float = 0.10      # s        (MATLAB :89, hardcoded)


@dataclass
class GaitDetector:
    p: GaitParams = field(default_factory=GaitParams)
    in_stance: bool = False
    prev_fz: float = 0.0
    last_fs: float = float("-inf")
    last_to: float = float("-inf")
    stance_start: float = float("-inf")
    fs_count: int = 0

    def update(self, t: float, fz: float) -> str:
        mag, mag_prev, th = abs(fz), abs(self.prev_fz), self.p.fz_threshold
        event = ""
        if not self.in_stance and mag_prev < th and mag >= th:
            if t - self.last_fs >= self.p.min_gait_cycle and t - self.last_to > self.p.min_since_to:
                self.in_stance, self.stance_start, self.last_fs = True, t, t
                self.fs_count += 1
                event = FS_VALID
            else:
                event = FS_NOISE
        # MATLAB runs the TO check in the same iteration (after FS); preserved.
        if self.in_stance and mag_prev >= th and mag < th:
            if t - self.stance_start >= self.p.min_stance:
                self.in_stance, self.last_to = False, t
                event = TO_VALID
            else:
                event = TO_NOISE
        self.prev_fz = fz
        return event

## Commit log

2026-10-02 docs: initial commit, filtered to code and docs in use
    Firmware v1, bumpem package (CLI + server), tests, scripts, docs,
    ESCON parameter files, 4-module cabling diagram (PNG).
    Reference PDFs, thesis, photos, legacy and tools stay local (D14).
2026-10-02 docs: carrier board v1 (KiCad, generated from netlist, ERC/DRC/parity clean)
    [bumpem-carrier-bom.csv, bumpem-carrier.kicad_pcb, bumpem-carrier.kicad_sch]
2026-10-02 docs: carrier board spacing (force tracks clear of socket pins, gaps >= 0.74 mm), module D active
    [bumpem-carrier.kicad_pcb, bumpem-carrier.kicad_sch]
2026-10-02 api: perturbation by angle (Vicon axes, split over neighbouring cables), geometry endpoint, bumpem perturb; module D back
    [bumpem-carrier.kicad_pcb, bumpem-carrier.kicad_sch]
2026-10-02 docs: IAA100 terminal pinout (24 V on pins 1/2) from Futek docs
2026-10-02 scripts: force_check.py, 45 s guided hand-pull check of the A/C/D force sensors (board stays disarmed)
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2026-10-05 docs: TODO front tower failure (48 V supply + shunt shorted), parts to order and checks first
2026-10-05 docs: broken tower diagnosis (old 48 V supply faulty, chopper passes meter tests, ESCON partly tested)
2026-10-05 docs: carrier board 45 deg bends, 0.5 mm pour gap, top/bottom PDFs + KiCad zip (makerspace review)
    [bumpem-carrier.kicad_pcb]
2026-10-05 docs: parts list (xlsx, prices + links, towers multiplier); carrier README terminal part no. 1715750
    [parts-list.xlsx]
2026-10-05 docs: parts list without 48 V / 24 V supplies (in stock)
    [parts-list.xlsx]
2026-10-05 docs: parts-to-buy.xlsx (ESCON, brake chopper, load cell, IAA100)
    [parts-to-buy.xlsx]
2026-10-05 docs: 4th IAA100 found (with 200 kg DYMH-103); parts-to-buy without amplifier
    [parts-to-buy.xlsx]
2026-10-05 scripts: force_check waits up to 5 s for data and says clearly when the Teensy stopped sending
2026-10-05 docs: carrier board pluggable module connectors (Phoenix MSTB 2,5 with flanges), board 154 x 96 mm
    [bumpem-carrier-bom.csv, bumpem-carrier.kicad_pcb, bumpem-carrier.kicad_sch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]
2026-10-05 docs: parts list, header link removed (unverified)
    [parts-list.xlsx]
2026-10-05 docs: TODO force calibration and closed loop after the carrier board; repair C ground wire now
2026-10-05 api: set channels to the mounted modules at connect (--modules, default ACD)
2026-10-05 api: set module channels as soon as the board is DISARMED if it wasn't at connect
2026-10-05 api: serialize connect/disconnect; per-connection ping stop (double connect crashed the ping thread)
    [server.py]
2026-10-05 api: explain a timeout when the board is stuck at power-up (DAC not found)
    [device.py]
2026-10-05 api: optional serial traffic log (BUMPEM_SERIAL_LOG=<file>) to diagnose missing replies
    [device.py]
2026-10-05 api: reader thread survives and logs errors (it stopped silently on the real board)
    [device.py]
2026-10-06 docs: no-reply timeouts traced to a bad USB port/cable (hub), not the server
2026-10-06 docs: module D hard pull traced to its setpoint − wire on the 3.3 V rail
2026-10-06 docs: module A no-pull was a loose pin contact
2026-10-06 docs: chopper 24 V powered test from the maxon DSR 70/30 instructions
2026-10-06 docs: broken tower chopper threshold 75 V vs 55 V on the working towers
2026-10-06 docs: broken tower chopper passes the 24 V powered test (threshold set to 55 V)
2026-10-06 docs: broken tower motor windings 1 / 0.9 / 0.9 Ω
2026-10-06 docs: broken tower chopper passes at 48 V
2026-10-06 docs: broken tower ESCON powers up at 48 V, ready (disabled) with the motor connected
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2026-10-07 api: 503 board_lost when the serial link is gone (was a bare 500)
2026-10-07 docs: towers use Rotec 90x90 heavy profiles, slot 10 (thesis said 80x80)
2026-10-07 docs: profile is 90x90 light B-type slot 10 (from a top photo), not the heavy Rotec one
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2026-10-07 hardware: IAA100 DIN-rail mount and RS-15 plate from datasheets; parts overview PDF with renders
2026-10-07 hardware: fit-check print (one of each part on one bed) + its PDF
2026-10-07 hardware: RSP-2000-48 end brackets (case 952D M4 holes, 10 mm air gap); added to fit check and PDFs
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2026-10-07 docs: TODO rewritten around PCB on 10-08 and printed parts on 10-12
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2026-10-14 docs: handbook for future students (LaTeX, Overleaf)
    Hardware review vs Stanford and thesis, parts bought, cabling maps,
    carrier PCB, software from firmware to UI, procedures, faults found.
    pytest limited to tests/.
2026-10-14 docs: ground bridge per tower (motor + ESCON + amplifier -> white wire)
2026-10-14 docs: handbook Part I build walkthrough following the Stanford guide
    ESCON setup now includes Store Parameters + power-cycle check (Stanford p. 30).
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2026-10-15 hardware: solder carrier sockets with male pin strips as jig, not the Teensy
2026-10-15 docs: B's replacement ESCON arrived and wired, 24 V open
2026-10-15 docs: B chopper-ESCON cable to be replaced with 1.5 mm2 wire
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2026-10-19 docs: 200 kg load cell is on tower B, what to check
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2026-10-19 hardware: print tower parts flat, key side down
    Standing on end they toppled halfway (4 failed prints at the makerspace).
2026-10-19 docs: BumpemUI GitHub URL in the handbook; fix printed-parts LaTeX
2026-10-19 gait: lab system is Vicon + GRAIL split belt, detect per foot
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2026-10-22 docs: RSP-2000 bracket B matches the datasheet (1 x M4 at the fan end)
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2026-10-22 hardware: RS-15 plate, move the end-stop-side M6 hole 8 mm out (head hit the stop)
2026-10-22 hardware: RS-15 plate, terminal-side M6 hole 25 mm further from the mains cables
2026-10-22 hardware: assembly guide with print list, new RS-15 plate and bracket B
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2026-10-22 hardware: PETG print settings, missing pad-ledge supports, M6 torque note
2026-10-22 hardware: print job 2 for the makerspace (handoff PDF + STLs zip)
2026-10-22 hardware: 48 V bracket B 20 mm longer past the fan end (room for the T-nuts)
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2026-10-22 hardware: print job as one STL per bed instead of a 3MF
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2026-10-23 hardware: ground bar plate for the ONPIRA V 1x12, in the tower set
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2026-10-27 firmware: sensor gain range 0.5-3 for module B's 200 kg load cell (fw 1.0.1)
2026-10-27 docs: status after breadboard tests, firmware 1.0.1 flashed, all four motors hold 4 N
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2026-10-28 docs: no-pull fault found (ESCON J6 wires one pin low), ESCON recordings
2026-10-28 hardware: picture guide to find where a motor unit slips
2026-10-28 hardware: manual to fix a slipping shaft collar (joint 3)
2026-10-28 hardware: drum disassembly guide on a labelled photo of tower B; status: B hub screw missing
2026-10-28 hardware: disassembly guide with exact drum bolts (Stanford build guide) and rope re-tying page
2026-10-29 docs: drum slip cause on B and C (set-screw collar works loose)
2026-10-29 docs, hardware: original part numbers; drive shaft is aluminium (flat is easy), guide updated
2026-10-29 docs: tower B drive shaft damaged under the set screw; plan steel D-shafts
2026-10-29 docs, hardware: drum collar is a clamp collar; fix = new smooth shaft, clean, threadlocker
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2026-11-02 docs: update.bat crashed after Y (brackets of the Python time call broke the for /f line): backup name from %date% %time%
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2026-11-05 gait: study contacts as the SLAP script, thresholds from plate noise, frame clock, next-contact prediction
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
